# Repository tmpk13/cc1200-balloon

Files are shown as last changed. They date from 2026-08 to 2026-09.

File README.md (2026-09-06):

# cc1200-balloon

High altitude balloon payload: a CC1200 sub-GHz telemetry downlink and an air
quality sensor stack, hosted by a Seeed Wio-E5 module.

The CC1200 radio and its 434 MHz matching network are carried over from the
v1 design (an import of the Altus Metrum TeleMini netlist). Everything else -
the STM32F042 host, the flash, the barometer, the pyro channels, the LDO,
the comparator and the buzzer - has been removed and replaced by the Wio-E5,
a GNSS receiver and the sensor set from `Forest-Balloon.csv`.

Schematic only. There is no PCB layout yet.

## Architecture

```mermaid
classDiagram
    direction LR

    class WioE5["U201 Wio-E5"] {
        STM32WLE5JC + SX126x
        SPI1 PB3 PB4 PB5
        I2C1 PB6 PB7
        USART2 PA2 PA3
        LPUART1 PC1
        ADC_IN0 PB13
        RFIO to J201 coax pads
    }
    class Power["Power"] {
        J101 battery pads 3.6 V max
        Q101 reverse block
        Q102 P-FET load switch
        SW101 on/off on the gate
        +BATT unregulated
    }
    class Radio["U301 CC1200"] {
        40 MHz X301
        PA and LNA match
        J301 coax pads
        SPI + CS + RESET + GPIO2
    }
    class GNSS["U401 AT6558R-5N32"] {
        26 MHz TCXO X401
        32.768 kHz X402
        internal DCDC L403
        active antenna bias-T
        J401 coax pads
        UART0 + 1PPS + ON_OFF
        C414 optional supercap
    }
    class I2CBus["I2C1 at 100 kHz"] {
        U501 SCD40 CO2 0x62
        U502 AS3935 lightning 0x03
        U503 BME688 0x76
        U504 BME688 0x77
    }
    class SPIBus["SPI1"] {
        U301 CC1200
        J501 BMV080 particulate
    }
    class Antenna["L501 100 uH loop"] {
        C505 910p + C506 47p
        R501 10k damping
        500 kHz resonant
    }

    Power --> WioE5 : +BATT
    Power --> Radio : +BATT
    Power --> GNSS : +BATT
    Power --> I2CBus : +BATT
    Power --> SPIBus : +BATT
    Power --> WioE5 : VBAT_SENSE
    WioE5 --> SPIBus : SPI_SCK MISO MOSI
    WioE5 --> Radio : RADIO_CS RST IRQ
    WioE5 --> I2CBus : SCL SDA
    WioE5 --> GNSS : GNSS_TX RX PPS ONOFF
    I2CBus --> WioE5 : LIGHTNING_IRQ
    SPIBus --> WioE5 : PM_CS PM_IRQ
    Antenna --> I2CBus : INP/INN
```

The generator pipeline, which is what `build.sh` runs:

```mermaid
flowchart LR
    subgraph src[sources]
        sheets[sheets/*.json<br/>components, nets, groups]
        scad[models/*.scad]
        parts[tools/gen_bom.ts<br/>value to MPN map]
    end
    subgraph lib[libraries]
        sym[gen_symbols.ts<br/>Wio-E5, CC1200+pin16,<br/>AT6558R, BMV080]
        fp[gen_footprints.ts<br/>WIO-E5, FPC-13,<br/>QFN-40, axial coil]
        d3[gen_3d.ts<br/>OpenSCAD to STL to WRL]
    end
    subgraph gen[generation]
        kv[kicad-vis<br/>placement]
        asm[assemble.ts<br/>hierarchy + root sheet]
        loc[localize.ts<br/>demote sheet-local globals]
        flags[fixflags.ts]
        patch[patchnets.ts]
        flow[flowbridge.ts<br/>flow-wire routing]
        lbl[fixlabels.ts<br/>label justification]
    end
    subgraph check[gates]
        cg[checkglobals.ts]
        cs[checkshorts.ts]
        cf[checkframe.ts]
        vn[verify_nets.ts]
        erc[kicad-cli ERC]
    end
    subgraph out[outputs]
        sch[*.kicad_sch]
        bom[BOM.md<br/>digikey_bom.csv]
    end

    sheets --> kv
    sym --> kv
    fp --> kv
    scad --> d3
    d3 --> fp
    kv --> asm --> loc --> flags --> patch --> flow --> lbl --> sch
    sch --> cg & cs & cf & vn & erc
    parts --> bom
    sheets --> bom
```

## Sheets

| Sheet | Contents |
| --- | --- |
| `power.kicad_sch` | battery solder pads, P-FET reverse block, SPDT switch driving a second P-FET as a soft-start load switch, battery sense divider, 4 mounting holes |
| `mcu.kicad_sch` | Wio-E5 module, decoupling, reset, coax pads for the module's own LoRa radio, SWD + console pads, status LED, I2C pull-ups |
| `radio.kicad_sch` | CC1200, 40 MHz crystal, per-pin decoupling, loop filter, the v1 TX/RX matching network, coax pads |
| `gnss.kicad_sch` | AT6558R-5N32, 26 MHz TCXO, 32.768 kHz RTC crystal, internal DCDC/LDO passives, active-antenna bias-T, coax pads, optional RTC backup supercapacitor |
| `sensors.kicad_sch` | SCD40, AS3935 with its 500 kHz loop antenna, two BME688 at different addresses, BMV080 ZIF connector |

## Power

There is no regulator. The battery drives the whole board through two
P-channel FETs in series:

```
J101 -- VBAT_IN -- Q101 (reverse block) -- VBATT -- Q102 (load switch) -- +BATT
          |                                  |            |
        D101 TVS                           C101 22u    C104 10u + C106 22u
```

`Q101` blocks a reversed battery: its source is on the load side, so the
body diode conducts battery to load and the channel shorts it out. That is
also why `Q101` cannot double as the on/off switch - the body diode keeps
the load powered whatever the gate does.

`Q102` is the switch, oriented the other way round (source on the battery
side), so its body diode blocks in the forward direction and an open channel
really does disconnect the load. `SW101` drives its gate: pole to `SW_ON`,
one throw to GND (on), the other to `VBATT` (off), so the gate is defined in
both positions. `R101` 100k holds the gate at the source - off - while the
switch is between contacts.

`R102` 10k and `C102` 1u slow the turn-on to about 9 ms, which holds the
inrush to roughly 30 mA. Without them the switch would connect about 70 uF
of rail and IC decoupling straight across the cell; a bobbin lithium cell
with ohms of internal resistance would collapse and the board would sit in
a brownout loop. The regulator's own soft start used to do this job.

The 10k has to stay small against the 100k pull-up or the gate never gets
there: on, the two divide `VBATT` and leave the gate at 9 % of it, so
Vgs is -3.3 V at a full cell and still -2.3 V at 2.5 V.

The `+BATT` rail is the battery, minus two Rds(on) drops - about 100 mR
total, so a few tens of millivolts at the currents this board draws.
Everything runs from it directly, so the supply follows the cell all the way
from full charge to cutoff.

| | |
| --- | --- |
| Rail | `+BATT`, unregulated |
| Maximum | 3.6 V |
| Off-state drain | `Q102` and `Q101` leakage only; the sense divider is on the switched side |
| On-state overhead | 33 uA in the `R101`/`R102` gate divider, 18 uA in the `R103`/`R104` sense divider |

## Wio-E5 pin map

All 18 usable module GPIO are allocated. `PA13`/`PA14` are SWD, `RST` is on
the debug header.

| Pin | Net | Function |
| --- | --- | --- |
| 8 PB3 | `SPI_SCK` | SPI1 clock, CC1200 + BMV080 |
| 7 PB4 | `SPI_MISO` | SPI1 MISO |
| 11 PB5 | `SPI_MOSI` | SPI1 MOSI |
| 26 PB14 | `RADIO_CS` | CC1200 chip select |
| 5 PB15 | `RADIO_RST` | CC1200 reset |
| 20 PB10 | `RADIO_IRQ` | CC1200 GPIO2 |
| 6 PA15 | `PM_CS` | BMV080 chip select |
| 25 PB9 | `PM_IRQ` | BMV080 interrupt |
| 10 PB6 | `SCL` | I2C1 clock |
| 9 PB7 | `SDA` | I2C1 data |
| 23 PA0 | `LIGHTNING_IRQ` | AS3935 interrupt (wake-capable) |
| 19 PA2 | `GNSS_RX` | USART2 TX to the receiver |
| 18 PA3 | `GNSS_TX` | USART2 RX from the receiver |
| 27 PA10 | `GNSS_PPS` | 1PPS |
| 13 PC0 | `GNSS_ONOFF` | receiver shutdown control |
| 12 PC1 | `DBG_TX` | LPUART1 console out, on the debug header |
| 24 PB13 | `VBAT_SENSE` | ADC_IN0, 1:2 divider off the switched `+BATT` rail |
| 21 PA9 | `STATUS_LED` | green LED through 1 k |
| 15 RFIO | `LORA_RF` | u.FL, the module's own sub-GHz radio |

The CC1200's GPIO0 and GPIO3 go to test pads (`TP301`, `TP302`) rather than
to the MCU; one interrupt line is enough for normal operation and there were
no pins left.

## No connectors

The payload is mass-limited, so nothing on this board mates with anything.
Every interface is a solder pad:

| Pad | Was | Carries |
| --- | --- | --- |
| `J101` | JST-PH 2-pos | battery leads, 3.0 mm pitch, + marked in silkscreen |
| `J202` | 1x06 2.54 mm header | SWD and console, six 1.27 mm pads |
| `J301` | SMA edge launch | CC1200 coax pigtail |
| `J401` | SMA edge launch | GNSS coax pigtail |
| `J201` | u.FL receptacle | Wio-E5 LoRa coax pigtail |

That is roughly 5 g back, most of it the two SMA edge launches. The coax
pads are a centre-conductor land with coplanar grounds either side and a
braid pad behind, so a pigtail lies flat and strain-relieves on the braid
pad.

The one connector left is `J501`, the 0.30 mm ZIF that the BMV080's flex
plugs into. It weighs about 0.05 g and Bosch specifies no other way to
attach the sensor, so it stays.

## Antennas

Three RF ports, all separate, all soldered:

- `J301` - CC1200, matched for 434 MHz by the v1 network.
- `J401` - GNSS. Expects an **active** antenna: the AT6558R data sheet asks
  for 18-35 dB of external gain, and `L401`/`C401` form the bias-T that
  feeds it from `ANT_BIAS`, with `C402` blocking the feed DC out of `RF_IN`
  and `L402` the series match into it. The BOM names an Abracon AANI-AP-0158-1, a
  27 x 27 mm adhesive patch with a 28 dB LNA and a 100 mm pigtail; cut its
  u.FL plug off and solder the coax to the pads.
- `J201` - the Wio-E5's own LoRa radio, independent of the CC1200 link.

## Optional RTC backup

`C414` is an unpopulated supercapacitor on the AT6558R's `VDD_BK` pin, for
GNSS hot start after a power interruption. The chip trickle-charges it
through its own internal circuit, and blocks it from discharging back into
the rail - no diode or series resistor needed, so it wires straight to the
pin.

`VDD_BK` is left floating when `C414` is not fitted, which is what the data
sheet asks for. The backup domain is still powered whenever the board is:
the chip feeds it internally from `VDD_IO` through a diode. Only the
*unpowered* hold needs the supercapacitor.

The named part is a KEMET FCS0V104ZFTBR24, 100 mF at **3.5 V**, which is
below the 3.6 V the `+BATT` rail can reach. The data sheet wants a backup
cell rated above `VDD_IO` + 0.3 V, so above 3.9 V here; pick a
higher-voltage part before fitting it. 100 mF holds the RTC and backup RAM
for roughly three hours, and costs about 1 g and a 10.7 mm circle of board
- which is why it is optional on a mass-limited payload.

## Regenerating

```sh
./build.sh                 # libraries, sheets, routing, all gates, ERC, BOM
SKIP_SOURCING=1 ./build.sh # same, without the live DigiKey pass
bun run tools/gen_bom.ts   # bom.json from sheets/*.json
tools/source_bom.py --boards 1 --planned 8
```

`build.sh` is deterministic: same inputs, byte-identical schematics. Edit
`sheets/*.json`, never the generated `.kicad_sch`.

The BOM step is separate because it needs network access and spends DigiKey
API quota. It reads live stock and pricing, and will substitute an
equivalent in-stock part when the preferred one has run out - checking the
parametric value and package first, so a request for 1 uF cannot come back
as 0.1 uF.

`tools/source_bom.py` needs `digi-mouse-search` and its virtualenv, which is
not installed on this machine, so `build.sh` reports the missing interpreter
and stops short of the sourcing pass. `bom.json` is still regenerated; the
stock and price columns in `BOM.md` are whatever the last successful run
read. Re-run the sourcing pass before ordering.

## Verification

`build.sh` fails on any of these:

| Gate | Result |
| --- | --- |
| kicad-vis placement | 5/5 sheets placed |
| flow-wire routing | 5/5 sheets, DRC 0 violations |
| cross-sheet global labels | no undeclared names shared between sheets |
| shorted rails | no electrical group carries two power symbols |
| footprint resolution | 27 distinct footprints, all present |
| frame fit | no sheet's content runs off its page |
| netlist vs `sheets/*.json` | 352 endpoints, 74 nets, exact match |
| full-hierarchy ERC | 0 errors, 2 warnings |

The two ERC warnings are the BME688 address straps: `U503.SDO` to GND and
`U504.SDO` to +BATT put a bidirectional pin on a power net, which is what
setting an I2C address on that part looks like.

The netlist comparison is the gate that matters. Placement and routing are
geometry, and geometry can join two rails without ERC calling it an error -
which is exactly what happened once during this design (see `NOTES.md`).

## Ordering

`digikey_bom.csv` holds **one board's worth**: 49 lines, three columns,
every line cut tape or bulk. Upload it to DigiKey's BOM Manager and set the
multiplier there rather than scaling the file - that way the pack and reel
rounding happens once, in DigiKey's hands, instead of being baked in here.

Two lines are deliberately absent from the CSV, because DigiKey cannot
fulfil them as uploaded:

- **C414** (supercapacitor) - do not populate; `399-13093-1-ND` if you want it.
- **U401 AT6558R-5N32** - not stocked at DigiKey at all. LCSC C500608.

Cost is $118.98 per board, of which $45 is off-board (the BMV080 module and
the GNSS antenna). Checked against an 8-board run, two lines are tight:
the BMV080 comes in packs of 10 and is discontinued at DigiKey, and the
56 nH match inductor has 59 in stock against the 16 the run needs.

## Known limitations

- **The rail is unregulated and can touch 3.6 V.** That is the absolute
  maximum operating supply for both the Wio-E5's STM32WLE5 and the CC1200,
  so there is no headroom left: a cell that rests above 3.6 V, or a charger
  left connected, is over the limit. Confirm the cell's open-circuit voltage
  before connecting it.
- **No brownout floor either.** With the regulator gone the rail falls with
  the cell instead of holding 3.3 V to cutoff, so the RF output power, the
  ADC reference and the sensor readings all drift over a flight. `VBAT_SENSE`
  measures the rail itself, which at least makes the drift observable.
- **The GNSS goes out of spec before the rest of the board.** `VDD_IO` and
  `DX_IN` on the AT6558R are specified 2.7-3.6 V, and its power-on reset
  releases at about 2.45 V. The receiver is therefore the first thing to
  stop as the cell sags, and it stops without warning the MCU - budget the
  flight on the 2.7 V point, not on the cell's cutoff.
- **`D101` no longer protects the ICs.** The SMF6.5A was sized for the old
  1.8-5.5 V regulator input; it does not start conducting until about 7 V,
  well past the 3.9 V absolute maximum of the parts now sitting directly on
  the rail. It is a gross-overvoltage guard, not IC protection, and no
  standoff low enough to help would sit safely above a fresh cell.
- **GNSS altitude limit.** The AT6558R data sheet says nothing about COCOM
  limits. Most consumer receivers stop reporting above 18 km or 515 m/s,
  which is below balloon float altitude. Confirm the firmware's behaviour
  before flying, or plan on a receiver with an explicit airborne mode.
- **BMV080 mating connector.** The land pattern for the 0.30 mm pitch
  KYOCERA 6844 connector was derived from the series drawing, not from a
  vendor-supplied library. Check it against Kyocera's own recommendation
  before fabrication.
- **SCD40 in a balloon.** The sensor is specified from -10 C and its NDIR
  reading is pressure-dependent; at float altitude both are out of range
  without compensation from the BME688 pressure channel.
- No PCB layout, no thermal design, no antenna measurements.

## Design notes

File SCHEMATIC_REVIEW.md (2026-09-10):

# Schematic review: cc1200-balloon

Reviewed at commit `0d6f3e7` ("Clean up schematic. Add component groups to PCB.").
Reference design for the CC1200 supply work: `~/telemini/` (Altus Metrum TeleMini 3.0a).

## Verdict

Two blocking defects, both introduced by the hand-edit in `0d6f3e7`:

1. **The Power sheet has been emptied.** Ten parts were deleted, including the
   on/off switch and the entire load-switch path. The board has no way to be
   turned off and no bulk capacitance at the load.
2. **`SCL` and `SDA` are swapped at all four I2C devices.** The bus cannot work
   as drawn.

Everything else checks out. Outside those two faults the schematic is an exact
electrical match to `sheets/*.json`, the CC1200 support circuitry and the
434 MHz match reproduce TeleMini component-for-component, and the AT6558R
wiring matches the data sheet in `ref/`.

The PCB has **zero routed traces**, so fixing both costs no layout rework.

## Method

- Exported the flat netlist from the current `.kicad_sch` set with
  `kicad-cli sch export netlist` (107 components, 92 nets).
- Compared the resulting pin-to-net partition against `sheets/*.json`, the
  generator's source of truth, normalising the pin numbering of two-pin
  passives so that a flipped capacitor does not read as a difference.
- Cross-checked the CC1200 support parts and the RF match against the TeleMini
  netlist, and its capacitor placement against `telemini.pcb` element geometry.
- Checked the AT6558R against `ref/AT6558R-5N32.pdf` (pin table section 2.2,
  power scheme 3.2, reference design 7.1, BOM 7.2).
- Parsed `cc1200_balloon.kicad_pcb` and confirmed its net assignments match the
  schematic exactly, then measured every CC1200 support part's pad-to-pin
  distance.

Full-hierarchy ERC reports **0 violations**. Neither defect below is the kind
ERC can see: a swapped pair of same-type pins and a deleted subcircuit both
leave a perfectly legal schematic.

---

## 1. The Power sheet is empty (blocking)

`power.kicad_sch` is a 301-byte stub with no components. Some of its parts
migrated into `mcu.kicad_sch`; the rest were deleted outright.

| Ref | Value | Function | Status |
| --- | --- | --- | --- |
| `J101` | BATT pads | battery input | moved to MCU sheet |
| `Q101` | DMG3401LSN-7 | reverse-block P-FET | moved to MCU sheet |
| `R103` `R104` `C107` | 100k 100k 100n | battery sense divider | moved to MCU sheet |
| `H101`-`H104` | M2.5 | mounting holes | moved to MCU sheet |
| `D101` | SMF6.5A | input TVS | **deleted** |
| `C101` | 22u | `VBATT` bulk | **deleted** |
| `SW101` | JS102011SAQN | on/off switch | **deleted** |
| `Q102` | DMG3401LSN-7 | load switch P-FET | **deleted** |
| `R101` `R102` `C102` | 100k 10k 1u | gate bias and soft start | **deleted** |
| `C104` `C106` | 10u 22u | `+BATT` bulk | **deleted** |
| `C203` | 10u | Wio-E5 bulk (MCU sheet) | **deleted** |

Consequences:

- **No power switch.** The board is live whenever the cell is connected.
- **No soft start.** The `R102`/`C102` ramp that held inrush to ~30 mA is gone.
- **No input TVS.**
- **`VBATT` and `+BATT` have merged.** `Q101` source now feeds `+BATT`
  directly. Reverse-battery protection survives — that was `Q101`'s job — but
  it is now the only thing between the cell and the whole board.
- **The rail lost 42 uF of its 76 uF.** `+BATT` is down to 34 uF, and 22 uF of
  that is `C502` at the SCD40, 13.6 mm away from the CC1200. The radio's own
  local bulk is `C312`, a single 1 uF at 5.2 mm. That is thin for a part that
  pulls ~120 mA in TX bursts from a bobbin cell with ohms of internal
  resistance — the exact brownout loop `README.md` describes.

```mermaid
flowchart LR
    subgraph des["as designed in sheets/*.json"]
        J1[J101] --> D1[D101 TVS] --> Q1[Q101<br/>reverse block]
        Q1 --> VB[VBATT<br/>C101 22u]
        VB --> Q2[Q102<br/>load switch]
        SW[SW101 + R101<br/>R102 + C102] --> Q2
        Q2 --> BT[+BATT<br/>C104 10u + C106 22u]
    end
    subgraph drw["as drawn in the schematic today"]
        J1b[J101] --> Q1b[Q101<br/>reverse block] --> BTb[+BATT<br/>no local bulk]
    end
```

**Fix.** Restore the deleted parts. `sheets/power.json` still holds the correct
netlist for all of them, so the content is not lost — see section 5 for how to
get it back without losing the PCB work.

---

## 2. SCL and SDA are swapped at every I2C device (blocking)

The MCU end is right and all four device ends are wrong, so the clock line
lands on the sensors' data pins and vice versa.

| Net as drawn | MCU | SCD40 `U501` | AS3935 `U502` | BME688 `U503`/`U504` |
| --- | --- | --- | --- | --- |
| `SCL` | pin 10 `PB6` — clock, correct | pin 10 **SDA** | pin 13 **MOSI/SDA** | pin 3 **SDI** |
| `SDA` | pin 9 `PB7` — data, correct | pin 9 **SCL** | pin 11 **SCL** | pin 4 **SCK** |

`sheets/sensors.json` has it right (`SCL` to `U501.9 U502.11 U503.4 U504.4`),
so this is a regression introduced when the sheet was edited by hand, not a
source error. The pull-ups `R203`/`R204` follow the swapped nets, so both lines
are still pulled up — nothing else masks it.

**Fix.** The whole error is two global labels in `sensors.kicad_sch`:

- `SDA` at `328.93, 269.24`
- `SCL` at `328.93, 274.32`

Swapping those two label texts corrects all four devices at once. The board
carries the same swap (PCB nets match the schematic exactly), so re-import the
netlist afterwards — with no traces routed, nothing else has to move.

---

## 3. Everything else verified correct

These were checked against a reference and found sound; no action needed.

**CC1200 `U301`** — all 33 pins match the data sheet function assignment and
the TeleMini wiring: supplies on pins 1/5/12/13/15/22/25/27/28, the four
internal-regulator decoupling pins 6/21/26/29, `RBIAS` 56k on pin 14, the
1.8 nF loop filter across LPF0/LPF1 (23/24), `EXT_XOSC` (32) grounded for
crystal operation, and the exposed pad on GND.

**434 MHz match** — reproduces TeleMini node for node, including the two easy
things to get wrong: `C322` 2p2 sits in *parallel* with `L302` 15n (TeleMini
`C176` across `L172`), and `L307` 27n shunts LNA_P to ground while `L308` 27n
returns LNA_N to the RX node. All sixteen values carry over unchanged.

**AT6558R `U401`** — matches `ref/AT6558R-5N32.pdf` throughout. `VDD_IO` (7)
and `DX_IN` (21) on the rail; `VCORE` (23) fed from `DX_OUT` (22) through
`L403`; the LDO output pins each decoupled to the value the pin table names
(`VDD_ANA` 1 uF, `VX_OUT` 0.1 uF); `TEST` (29) pulled low and `ON_OFF` (30)
driven, both as specified; `nRST` (17), `GPIO8` (8) and `GPIO16` (33) left
floating, which is what the data sheet requires. The 32.768 kHz crystal
correctly has no load caps. `ANT_BIAS` uses the 33 nH + 0.1 uF feed the data
sheet names.

**UART crossing** — `PA2` (USART2 TX) reaches `GPIO1/RXD0`, `PA3` (USART2 RX)
reaches `GPIO0/TXD0`, each through the 22R the reference design shows. Correct
in the direction that is usually wrong.

**I2C addressing** — AS3935 `AD0`/`AD1` both high gives 0x03; BME688 `SDO` low
gives 0x76 and high gives 0x77; both BME688 `CSB` pins high select I2C. All
match `README.md`.

**Interrupts** — `PA0`, `PB9`, `PB10` use EXTI lines 0, 9 and 10. No two
interrupt sources share a line.

**Status LED** — `D201` cathode to GND, anode through `R202` 1k to `PA9`.
Correct polarity for a high-side drive.

---

## 4. Worth confirming before fabrication

Three items I could not settle from material on this machine.

**AS3935 regulator configuration.** `Vdd` (5) and `VReg` (6) are both tied to
`+BATT` with `EN` (7) grounded — the "internal regulator bypassed" arrangement,
which the ams application circuits specify for a *regulated 2.5 V* supply, not
for a rail that reaches 3.6 V. There is no AS3935 data sheet in `ref/` and
`NOTES.md` does not record the reasoning. Check whether this part wants
`EN_VREG` tied high on an unregulated rail. Separately, `C503` (10u) sits on
`ACG` (1) rather than on `VReg`; confirm that is where the data sheet wants it.

**CC1200 crystal load caps.** `C318`/`C319` are 12p against TeleMini's 10p, and
the crystal changed with them (`CX3225SB40000D0FPLCC` here, an ABM12 in
TeleMini). `NOTES.md` says the load caps were "kept from v1", which is not
quite what happened. Size them from the chosen crystal's CL: with ~3 pF of
stray, 12 pF caps present about 9 pF, so they suit a CL=9 pF part and pull a
CL=8 pF part low.

**`BOM.md` is stale.** It lists `C402` as 1u and `C411` as 10u, and references
`C417`-`C419`, none of which match `sheets/gnss.json` today. Regenerate before
ordering.

---

## 5. CC1200 supply decoupling: which capacitor goes at which pin

This is the layout list. The schematic puts all nine 47 nF caps on one `+BATT`
net with no pin association, so the assignment has to be made here and carried
into placement by hand.

`U301` is a QFN-32, 5x5 mm, 0.5 mm pitch, at `90.0, 108.65` rotated -90 deg on
`F.Cu`. Pin coordinates below are the board coordinates as placed today.

### The nine rail capacitors — one per supply pin

Assignment follows refdes order against pin order, which is how `NOTES.md`
describes the intent ("the nine supply decoupling caps"):

| Cap | Value | Pin | Function | Pad at | Package edge |
| --- | --- | --- | --- | --- | --- |
| `C301` | 47n | 1 | `VDD_GUARD` | `91.75, 106.21` | top |
| `C302` | 47n | 5 | `DVDD` | `89.75, 106.21` | top |
| `C303` | 47n | 12 | `DVDD` | `87.56, 108.40` | left |
| `C304` | 47n | 13 | `AVDD_IF` | `87.56, 108.90` | left |
| `C305` | 47n | 15 | `AVDD_RF` | `87.56, 109.90` | left |
| `C306` | 47n | 22 | `AVDD_SYNTH1` | `90.75, 111.09` | bottom |
| `C307` | 47n | 25 | `AVDD_PFD_CHP` | `92.44, 110.40` | right |
| `C308` | 47n | 27 | `AVDD_SYNTH2` | `92.44, 109.40` | right |
| `C309` | 47n | 28 | `AVDD_XOSC` | `92.44, 108.90` | right |

Each one goes on the same layer as the part, hot pad facing its supply pin,
ground pad onto the ground pour with its own via — never daisy-chained through
a neighbour's via. The nine pins sit on all four edges of the package, so the
caps must ring it. TeleMini achieved 0.8-2.2 mm pad-to-pin; treat 2 mm as the
ceiling.

TeleMini used seven 47 nF for these nine pins, letting one cap serve pins 27
and 28 and another serve 12 and 13. This design has nine, one each, which is
the better arrangement — keep it.

### The four internal-regulator capacitors — closest of all

These decouple regulators *inside* the chip. They are not on the rail, and they
matter more than the nine above.

| Cap | Value | Pin | Function | Pad at | TeleMini equivalent |
| --- | --- | --- | --- | --- | --- |
| `C313` | 220n | 6 | `DCPL` | `89.25, 106.21` | `C42` 0.22uF |
| `C314` | 10n | 21 | `DCPL_VCO` | `90.25, 111.09` | `C211` 0.01uF |
| `C315` | 47n | 26 | `DCPL_PFD_CHP` | `92.44, 109.90` | `C261` 47nF |
| `C316` | 47n | 29 | `DCPL_XOSC` | `92.44, 108.40` | `C291` 47nF |

`C314` on `DCPL_VCO` is the one to place first — it is the VCO's supply and it
sits on the bottom edge between the LNA pins and `AVDD_SYNTH1`, which is
crowded. TeleMini got all four to 2.0-3.4 mm.

### Rail-level capacitors — not per-pin

| Cap | Value | Where it goes |
| --- | --- | --- |
| `C312` | 1u | bulk, where `+BATT` enters the radio block, ahead of the ring of 47n |
| `C311` | 10n | with `C312`, or near `AVDD_RF` (pin 15) — TeleMini's `C171` was closest to that pin |
| `C310` | 100p | near `AVDD_RF` (pin 15) — TeleMini's `C172`, the fastest cap in the set |

**`C320` (56p) is not a decoupling capacitor.** It sits in parallel with `R302`
18R across the PA bias feed, exactly as TeleMini's `C173` parallels `R171`.
Place it beside `R302`, not at a chip pin.

### Also close to their pins

`C317` 1n8 straddles pins 23/24 with the shortest possible loop; `C318`/`C319`
and `X301` form the 40 MHz oscillator at pins 30/31; `R301` 56k sits at pin 14.

### What the current PCB does

All twelve rail capacitors are bunched off the top edge of the package, and the
four regulator capacitors are 6-11 mm away:

| Part | Should be at | Nearest supply pin today | Distance |
| --- | --- | --- | --- |
| `C301`-`C309` | ringing the package | pins 1 and 5 only, all nine | 2.1-4.8 mm |
| `C310` `C311` `C312` | rail entry / pin 15 | pins 1 and 5 | 4.6-5.3 mm |
| `C313` | pin 6 | — | 6.2 mm |
| `C314` | pin 21 | — | 11.1 mm |
| `C315` | pin 26 | — | 9.7 mm |
| `C316` | pin 29 | — | 10.0 mm |

Nothing is placed on the left, bottom or right edges. Pins 12, 13, 15, 22, 25,
27 and 28 have no capacitor near them at all. This needs redoing before the
board is routed.

Better already: `R301` at 1.4 mm, `C319` at 1.4 mm, `C318` at 1.9 mm, `C317` at
1.7-2.0 mm, `C325` at 1.9 mm. The TX chain is loose — `L301` 5.4 mm and `C321`
6.2 mm from pin 17 — and should be tightened while the decoupling is moved.

---

## 6. Suggested order of work

1. Swap the two global labels in `sensors.kicad_sch` — smallest fix, largest
   consequence.
2. Restore the power section. `sheets/power.json` is intact, so the cleanest
   route is to regenerate `power.kicad_sch` alone rather than running
   `build.sh`, which rewrites all five sheets and would discard the rest of the
   hand-editing in `0d6f3e7`. Restore `C203` on the MCU sheet at the same time.
3. Re-import the netlist into the PCB and place the restored parts.
4. Redo the CC1200 decoupling placement per section 5 before routing.
5. Resolve the three items in section 4.
6. Regenerate `BOM.md`.

### A note on the generator

`sheets/*.json` and the `.kicad_sch` files have diverged: the schematics are
now hand-edited and the JSON is not. `build.sh` regenerates all five sheets
from the JSON unconditionally, so running it restores the power section and the
correct I2C wiring but discards every other change made in `0d6f3e7`. Decide
which direction is authoritative before running it. (`assemble.ts` merges into
`.kicad_pro` rather than overwriting it, so the ERC pin map and severities
configured in the GUI are safe either way.)

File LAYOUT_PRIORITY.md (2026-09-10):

# CC1200 layout: what to keep short, in priority order

Companion to `SCHEMATIC_REVIEW.md`. Measured against the working tree on top of
`d4266bb`, with `U301` at `66.15, 138.95` rotated -90 deg.

**Context.** All 41 radio-block parts are currently staged outside the board
outline (the outline is 50 x 30 mm at x 75..125, y 85..115). The relative
placement inside the block is already largely right — the nine supply caps ring
the package at 1.2-2.0 mm and the match chain's internal hops are 1.0-1.6 mm.
What follows is the order to preserve when the block is brought onto the board.

## The number that sets the ranking

A narrow trace over a plane runs about **0.8 nH/mm**, and a via adds about
0.4 nH. At 434 MHz that is **~2.2 ohm of series reactance per millimetre**.

The same millimetre costs different amounts depending on what it is in series
with, which is the whole basis of the ranking below:

- **In a decoupling path** it lowers the capacitor's self-resonant frequency.
  A 47n 0402 has ~0.7 nH of its own ESL and resonates near 28 MHz. Add 2 mm of
  trace and a via — 2.0 nH — and it resonates near 14 MHz instead. The cap is
  half as effective at exactly the frequencies the chip's internal regulators
  care about, and the schematic looks identical.
- **In the match network** it is an unplanned series element. `C322` is 2.2 pF
  and `L302` is 15 nH; a stray 4 nH between them is a 27 % error in the
  inductor.
- **On the 40 MHz reference** it is mostly stray capacitance pulling frequency,
  and a crosstalk aperture. Reference phase noise multiplies to the carrier by
  20*log10(434/40) = **+20.7 dB**.
- **On SPI at 10 MHz** it costs nothing measurable.

---

## The ranking

| # | Keep short | Target | Now | Status |
| --- | --- | --- | --- | --- |
| 1 | `GND_EP` (33) down to the ground planes | via array in the pad | **0 vias** | **do first** |
| 2 | `C314` 10n to pin 21 `DCPL_VCO` | <=1.0 mm | 1.23 mm | close |
| 3 | `C316` 47n to pin 29 `DCPL_XOSC` | <=1.0 mm | 2.10 mm | tighten |
| 4 | `C315` 47n to pin 26 `DCPL_PFD_CHP` | <=1.0 mm | 3.09 mm | tighten |
| 5 | `C313` 220n to pin 6 `DCPL` | <=1.5 mm | 2.63 mm | tighten |
| 6 | `L301` 56n to pin 17 `PA` | <=1.5 mm | 6.22 mm | **worst in TX** |
| 7 | `C325`/`L306`/`L307`/`C326`/`L308` to pins 19/20, **P and N matched** | <=2.0 mm, legs within 0.3 mm | 1.8-6.0 mm, unbalanced | **worst in RX** |
| 8 | `C323` 5p1 to pin 18 `TRX_SW` | <=1.5 mm | 6.62 mm | tighten |
| 9 | `X301` + `C318`/`C319` to pins 30/31 | xtal <=2.5 mm, caps between | 4.0-5.5 mm | tighten |
| 10 | `R301` 56k to pin 14 `RBIAS` | <=2.0 mm | 3.31 mm | tighten |
| 11 | `C317` 1n8 across pins 23/24 `LPF0`/`LPF1` | <=1.5 mm | 1.4-1.6 mm | ok |
| 12 | Analog rail caps: pins 15, 28, 22, 27, 25, 13 | <=1.5 mm | 1.33-1.81 mm | ok, see note |
| 13 | Digital rail caps: pins 5, 12, 1 | <=2.0 mm | 1.21-1.79 mm | ok |
| 14 | Match chain internal hops, in schematic order | <=2.0 mm each | 1.0-1.6 mm | ok |
| 15 | `C310` 100p, rail | <=3 mm, near pin 15 | 7.64 mm | bring in |
| 16 | `C311` 10n / `C312` 1u, rail bulk | <=8 mm | 6.6 / 5.5 mm | ok |
| 17 | `L304` to `J301`, the only 50-ohm section | impedance, not length | 3.22 mm | see note |
| 18 | SPI (7,8,9,11), `RESET_N` (2), GPIO (3,4,10), test points | no constraint | — | route last |

---

## Why each tier sits where it does

### 1. The exposed pad, before anything else

`GND_EP` is the return path for every current in the chip, so it defines what
"short" even means for the seventeen items below it. Until it is solid,
tightening a decoupling cap buys less than the measurement suggests: the cap's
ground has to travel laterally around the package to find a via, and that path
is in series with the cap.

The pad is set up correctly in the footprint — 3.45 mm, `pad_prop_heatsink`,
`zone_connect 2`, on the `GND` net — and the `GND` zone is poured on all four
layers. But there are **4 vias on the entire board** and none of them are in
the pad, so the pad currently only reaches the `F.Cu` pour. Put a via array in
it (a 3x3 of 0.3 mm drill on ~1.2 mm pitch fits the 3.45 mm pad) and add a ring
of ground vias just outside the pin ring, tightest along the RF edge.

This is also the item with the shortest length that matters: the ~1.5 mm of
via barrel from the pad to `In1.Cu`.

### 2-5. The four `DCPL` pins

These are **not** rail decoupling. They are the outputs of regulators inside
the chip, and their capacitors are those regulators' compensation. Series
inductance here does not just filter worse, it moves a pole in a control loop
that was compensated assuming a low-impedance capacitor.

They rank above the RF path because they sit upstream of it — the VCO
regulator's noise is on the carrier before the carrier ever reaches pin 17.
Within the four:

- **`DCPL_VCO` (21)** — the VCO supply. Straight to phase noise and spurs.
- **`DCPL_XOSC` (29)** — the reference oscillator's supply, and whatever lands
  here gets the +20.7 dB multiplication to 434 MHz.
- **`DCPL_PFD_CHP` (26)** — inside the PLL loop, so in-band.
- **`DCPL` (6)** — digital core. Least sensitive of the four, but still a
  regulator output.

`C314` is already at 1.23 mm; the other three drifted when the block was
rearranged. Note `DCPL_VCO` (21) sits on the bottom edge wedged between the LNA
pins and `AVDD_SYNTH1` — it is the crowded one, so place it before its
neighbours rather than after.

### 6-8. The RF pins

`L301` at pin 17 is the first element of the TX match and carries both the DC
supply and the full RF output. 6.22 mm of trace is ~5 nH against a 56 nH
element — a 9 % error in the value that sets the PA's load impedance, which
comes straight off output power and efficiency. Since the stated job of this
board is a telemetry **downlink**, that is the millimetre that costs the most
link budget, which is why it ranks above the LNA.

The LNA pair at 7 has two separate requirements and the second is easy to miss:

- **Short**, because loss ahead of the LNA adds to noise figure dB for dB.
- **Balanced**, because the LNA is differential. `L306` 56n bridges pins 19 and
  20 and should straddle them symmetrically; `L307`/`C325` on the P leg and
  `L308`/`C326` on the N leg should mirror each other. Right now the P leg
  averages 4.22 mm and the N leg 4.66 mm with individual parts from 1.8 to
  6.0 mm, so the two legs are visibly unequal. Imbalance converts common-mode
  noise into differential signal and degrades image rejection, and no amount of
  tuning the values fixes it.

If uplink or commanding matters as much as the downlink, swap 6 and 7.

`C323` at pin 18 carries full TX power through the switch node in transmit.
`L305` is already fine at 2.05 mm; `C323` is the one at 6.62 mm.

### 9-10. The high-impedance nodes

The 40 MHz crystal group is now the worst-placed sensitive cluster —
`X301` 5.46 mm, `C318` 4.13 mm, `C319` 3.96 mm. Two things go wrong at that
distance: stray capacitance adds to a 12 pF load and pulls the frequency, and
a long high-Q node is both a crosstalk victim and an aggressor. Put the load
caps *between* the crystal and the pins, not beyond the crystal, and return
their grounds into the same via region as the exposed pad. The load caps are
also worth re-checking against the crystal's CL — see section 4 of the review.

`R301` is 56k, which makes `RBIAS` the highest-impedance node on the part and
the best antenna on the board. It sets every internal bias current. Keep it
under 2 mm, and keep it away from the crystal and the match chain rather than
merely short.

### 11-13. Decoupling and the loop filter

`C317` across the loop filter pins is already good. The nine rail caps are the
part of the current placement that is already right: every supply pin has a
47n within 1.21-1.97 mm and they ring all four edges.

One reassignment worth making: **`C308` is currently serving both pin 12
(1.79 mm) and pin 13 (1.81 mm) while `C309` sits redundantly near pin 12
(1.97 mm, and 2.24 mm from pin 13).** Move `C309` onto pin 13 `AVDD_IF` so each
of the nine pins has its own cap, which is what the nine were bought for.
Ground each cap with its own via — never daisy-chain two caps through one.

Analog pins rank above digital ones because `AVDD_RF`, `AVDD_XOSC`,
`AVDD_SYNTH1/2` and `AVDD_PFD_CHP` feed the blocks whose noise ends up on the
carrier, while `DVDD` and `VDD_GUARD` feed logic.

### 14. The chain, not the parts

The match network's internal hops are already 1.0-1.6 mm and in schematic
order. Preserve that as a block when it moves. The failure mode is spreading
the chain out or reordering it — the lumped values assume the elements are
adjacent.

### 17. The one place length is the wrong question

Everything from pin 17 through `L304` runs at match-network impedances that are
not 50 ohm, so "controlled impedance" is meaningless there and short is the
only rule. **`L304` to `J301` is the exception** — that section is at 50 ohm and
should be a proper coplanar microstrip with ground either side and stitching
vias along it. Getting its impedance right matters more than shaving a
millimetre off it.

### 18. Everything else

SPI, reset, the GPIO test points and `EXT_XOSC` have no length constraint worth
naming at these speeds. Route them last and use them as the escape path. The
only rule is negative: keep them out of the crystal area and do not let them
cross the LNA or PA traces.

---

## Suggested order of work

1. Via array in `GND_EP`, plus a ground via ring outside the pin ring.
2. Bring the radio block onto the board as a unit, keeping its internal
   arrangement.
3. Tighten `C315`, `C316`, `C313` onto their pins.
4. Pull `L301`/`C321` and `C323` up to pins 17 and 18.
5. Rebuild the LNA cluster symmetrically about pins 19/20.
6. Bring the crystal group in to <=2.5 mm.
7. `R301` to <2 mm, `C310` to <3 mm.
8. Move `C309` onto pin 13.
9. Route the 50-ohm run to `J301` last, with stitching.

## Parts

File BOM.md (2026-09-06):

# cc1200-balloon bill of materials

52 lines, 117 placements.

**Quantities are for 1 board. Set the multiplier in DigiKey's BOM Manager rather than scaling this file** - per-line quantities here are one board's worth, and nothing is rounded up to a pack or a reel.

DigiKey stock and pricing read live; totals are indicative, not a quote.

**STALE - do not order from this file.** It still describes the GNSS sheet as it was before the 2026-09-06 AT6558R rewiring, so its designators, quantities and line count are all wrong (`C415`-`C422`, `R404`, `R405` no longer exist; `C414`, `R402`, `R403` and the new inductor and oscillator part numbers are missing). Offers were read on 2026-08-25 and the sourcing pass cannot run on this machine (`/home/tmpk/digi-mouse-search` is gone), so nothing here can be refreshed until it is reinstalled. `bom.json` is current and correct. Re-run `tools/source_bom.py` before ordering.

**Board total (excluding DNP): $118.98**

| Refs | Value | MPN | Manufacturer | Package | Qty | DigiKey | Packaging | Stock | Unit | Source |
| --- | --- | --- | --- | --- | --- | --- | --- | --- | --- | --- |
| C101 C106 C502 | 22u | LMK212BBJ226MD-T | Taiyo Yuden | C_0805_2012Metric | 3 | 587-5917-1-ND | Cut Tape (CT) | 7124 | $0.3000 | substituted |
| C102 C202 C312 C402 C405 C409 C412 C417 C418 C419 C504 C511 C512 C513 | 1u | LMK105BJ105KVHF | Taiyo Yuden | C_0402_1005Metric | 14 | 587-3712-1-ND | Cut Tape (CT) | 754503 | $0.0560 | substituted |
| C104 C203 C411 C503 | 10u | GRM188R60J106KE47D | Murata Electronics | C_0603_1608Metric | 4 | 490-12538-1-ND | Cut Tape (CT) | 49549 | $0.1200 | substituted |
| C107 C201 C204 C403 C404 C406 C407 C408 C410 C413 C420 C421 C501 C507 C508 C509 C510 C514 | 100n | CL05B104KO5NNNC | Samsung Electro-Mechanics | C_0402_1005Metric | 18 | 1276-1001-1-ND | Cut Tape (CT) | 3698775 | $0.0170 | substituted |
| C301 C302 C303 C304 C305 C306 C307 C308 C309 C315 C316 | 47n | GRM155R71H473KE14D | Murata Electronics | C_0402_1005Metric | 11 | 490-10702-1-ND | Cut Tape (CT) | 990298 | $0.0230 | preferred |
| C310 C414 | 100p | GRM1555C1H101JA01D | Murata Electronics | C_0402_1005Metric | 2 | 490-5922-1-ND | Cut Tape (CT) | 504137 | $0.1100 | preferred |
| C311 C314 | 10n | GRM155R71H103KA88D | Murata Electronics | C_0402_1005Metric | 2 | 490-4516-1-ND | Cut Tape (CT) | 3203045 | $0.1000 | preferred |
| C313 | 220n | CL05A224KA5NNNC | Samsung Electro-Mechanics | C_0402_1005Metric | 1 | 1276-1455-1-ND | Cut Tape (CT) | 1670 | $0.1300 | preferred |
| C317 | 1n8 | GRM1555C1H182JA01D | Murata Electronics | C_0402_1005Metric | 1 | 490-GRM1555C1H182JA01DCT-ND | Cut Tape (CT) | 155404 | $0.1000 | preferred |
| C318 C319 | 12p | CL05C120JB5NNNC | Samsung Electro-Mechanics | C_0402_1005Metric | 2 | 1276-1178-1-ND | Cut Tape (CT) | 135682 | $0.1000 | preferred |
| C320 | 56p | GRM1555C1H560JA01D | Murata Electronics | C_0402_1005Metric | 1 | 490-1288-1-ND | Cut Tape (CT) | 907472 | $0.1000 | preferred |
| C321 | 39p | CC0402JRNPO9BN390 | YAGEO | C_0402_1005Metric | 1 | 311-1009-1-ND | Cut Tape (CT) | 239185 | $0.1000 | substituted |
| C322 | 2p2 | GRM1555C1H2R2CA01D | Murata Electronics | C_0402_1005Metric | 1 | 490-5932-1-ND | Cut Tape (CT) | 1537 | $0.1000 | preferred |
| C323 C325 C326 | 5p1 | GJM1555C1H5R1CB01D | Murata Electronics | C_0402_1005Metric | 3 | 490-3102-1-ND | Cut Tape (CT) | 167984 | $0.1000 | substituted |
| C324 | 6p2 | GJM1555C1H6R2BB01D | Murata Electronics | C_0402_1005Metric | 1 | 490-11231-1-ND | Cut Tape (CT) | 446597 | $0.1000 | substituted |
| C401 | 470p | GRM1555C1H471JA01D | Murata Electronics | C_0402_1005Metric | 1 | 490-1297-1-ND | Cut Tape (CT) | 654811 | $0.1000 | preferred |
| C415 C416 | 10p | GRM1555C1H100JA01D | Murata Electronics | C_0402_1005Metric | 2 | 490-5921-1-ND | Cut Tape (CT) | 435236 | $0.1000 | DNP preferred |
| C422 | 100m | FCS0V104ZFTBR24 | KEMET | SuperCap_KEMET_FCS_D10.7mm | 1 | 399-13093-1-ND | Cut Tape (CT) | 516 | $4.1300 | DNP preferred |
| C505 | 910p | GCM1555C1H911FA16J | Murata Electronics | C_0402_1005Metric | 1 | 490-GCM1555C1H911FA16JCT-ND | Cut Tape (CT) | 62670 | $0.1000 | substituted |
| C506 | 47p | CC0402JRNPO9BN470 | YAGEO | C_0402_1005Metric | 1 | 311-1021-1-ND | Cut Tape (CT) | 459310 | $0.1000 | substituted |
| D101 | SMF6.5A | SMF6.5A-TP | MCC (Micro Commercial Components) | D_SOD-123F | 1 | SMF6.5A-TPMSCT-ND | Cut Tape (CT) | 67741 | $0.4100 | preferred |
| D201 | STATUS | LTST-C191KGKT | Lite-On Inc. | LED_0603_1608Metric | 1 | 160-1446-1-ND | Cut Tape (CT) | 2695092 | $0.1500 | preferred |
| J401 | GNSS antenna | AANI-AP-0158-1 | Abracon LLC | mates J401 | 1 | 535-AANI-AP-0158-1-ND | Bulk | 465 | $7.2600 | off-board |
| J501 | BMV080 | 046844713002846+ | KYOCERA AVX | Kyocera_046844713002846_FPC-13_P0.30mm | 1 | 478-046844713002846+CT-ND | Cut Tape (CT) | 27269 | $0.8000 | preferred |
| J501 | BMV080 | BMV080 | Bosch Sensortec | mates J501 | 1 | 828-BMV080-10PC-ND | Box | 610 | $37.8680 | off-board |
| L301 L306 | 56n | LQW15AN56NG00D | Murata Electronics | L_0402_1005Metric | 2 | 490-6830-1-ND | Cut Tape (CT) | 59 | $0.1200 | preferred |
| L302 L305 | 15n | LQW15AN15NJ00D | Murata Electronics | L_0402_1005Metric | 2 | 490-1148-1-ND | Cut Tape (CT) | 112566 | $0.1100 | preferred |
| L303 | 43n | LQW15AN43NG00D | Murata Electronics | L_0402_1005Metric | 1 | 490-6817-1-ND | Cut Tape (CT) | 15740 | $0.1200 | preferred |
| L304 | 22n | LQW15AN22NG00D | Murata Electronics | L_0402_1005Metric | 1 | 490-6787-1-ND | Cut Tape (CT) | 626141 | $0.1200 | preferred |
| L307 L308 | 27n | LQW15AN27NG00D | Murata Electronics | L_0402_1005Metric | 2 | 490-6792-1-ND | Cut Tape (CT) | 92890 | $0.1200 | preferred |
| L401 | 33n | LQW15AN33NG00D | Murata Electronics | L_0402_1005Metric | 1 | 490-6804-1-ND | Cut Tape (CT) | 42256 | $0.1200 | preferred |
| L402 | 4n3 | LQW15AN4N3C00D | Murata Electronics | L_0402_1005Metric | 1 | 490-1138-1-ND | Cut Tape (CT) | 24339 | $0.1100 | preferred |
| L403 | 4u7 | LQM18PN4R7MFRL | Murata Electronics | L_0603_1608Metric | 1 | 490-12065-1-ND | Cut Tape (CT) | 243007 | $0.1700 | preferred |
| L501 | 100u | 78F101J-RC | Bourns Inc. | L_Axial_D2.8mm_L7.2mm_P10.16mm_Horizontal | 1 | M10136-ND | Bulk | 10421 | $0.2200 | preferred |
| Q101 Q102 | DMG3401LSN-7 | DMG3401LSN-7 | Diodes Incorporated | SOT-23 | 2 | DMG3401LSN-7DICT-ND | Cut Tape (CT) | 152236 | $0.5600 | preferred |
| R101 R103 R104 | 100k | RC0402FR-07100KL | YAGEO | R_0402_1005Metric | 3 | 311-100KLRCT-ND | Cut Tape (CT) | 7885509 | $0.1000 | preferred |
| R102 R201 R401 R402 R403 R501 | 10k | RC0402FR-0710KL | YAGEO | R_0402_1005Metric | 6 | 311-10.0KLRCT-ND | Cut Tape (CT) | 14582185 | $0.1000 | preferred |
| R202 | 1k | RC0402FR-071KL | YAGEO | R_0402_1005Metric | 1 | 311-1.00KLRCT-ND | Cut Tape (CT) | 8230169 | $0.1000 | preferred |
| R203 R204 | 4k7 | RC0402FR-074K7L | YAGEO | R_0402_1005Metric | 2 | 311-4.7KLRCT-ND | Cut Tape (CT) | 1184846 | $0.1000 | preferred |
| R301 | 56k | RC0402FR-0756KL | YAGEO | R_0402_1005Metric | 1 | 311-56.0KLRCT-ND | Cut Tape (CT) | 716428 | $0.1000 | preferred |
| R302 | 18R | RC0402FR-0718RL | YAGEO | R_0402_1005Metric | 1 | YAG3021CT-ND | Cut Tape (CT) | 279481 | $0.1000 | preferred |
| R404 R405 | 0R | RC0402JR-070RL | YAGEO | R_0402_1005Metric | 2 | 311-0.0JRCT-ND | Cut Tape (CT) | 11522810 | $0.1000 | preferred |
| SW101 | PWR | JS102011SAQN | C&K | SW_SPDT_CK_JS102011SAQN | 1 | 401-1999-1-ND | Cut Tape (CT) | 57487 | $0.9000 | preferred |
| U201 | Wio-E5 | 114993120 | Seeed Technology Co., Ltd | WIO-E5 | 1 | 1597-114993120-ND | Box | 682 | $7.1100 | preferred |
| U301 | CC1200 | CC1200RHBR | Texas Instruments | Texas_RHB0032E_VQFN-32-1EP_5x5mm_P0.5mm_EP3.45x3.45mm | 1 | 296-38892-1-ND | Cut Tape (CT) | 5460 | $5.4300 | preferred |
| U401 | AT6558R-5N32 | AT6558R-5N32 |  | AT6558R_QFN-40-1EP_5x5mm_P0.4mm_EP3.4x3.4mm | 1 | - | - | - | - |  |
| U501 | SCD40-D-R2 | SCD40-D-R2 | Sensirion AG | Sensirion_SCD4x-1EP_10.1x10.1mm_P1.25mm_EP4.8x4.8mm | 1 | 1649-SCD40-D-R2CT-ND | Cut Tape (CT) | 3564 | $18.6600 | preferred |
| U502 | AS3935-BQFT | AS3935-BQFT | ScioSense | QFN-16-1EP_4x4mm_P0.65mm_EP2.7x2.7mm | 1 | AS3935-BQFTCT-ND | Cut Tape (CT) | 1426 | $9.3500 | preferred |
| U503 U504 | BME688 | BME688 | Bosch Sensortec | Bosch_LGA-8_3x3mm_P0.8mm_ClockwisePinNumbering | 2 | 828-BME688CT-ND | Cut Tape (CT) | 9011 | $8.9900 | preferred |
| X301 | 40MHz | CX3225SB40000D0FPLCC | KYOCERA AVX | Crystal_SMD_3225-4Pin_3.2x2.5mm | 1 | 478-CX3225SB40000D0FPLCCCT-ND | Cut Tape (CT) | 1614 | $0.8100 | preferred |
| X401 | TCXO 26MHz | UCF4031035LK005000-26MDK | Pletronics, Inc | Oscillator_SMD_ECS_2520MV-xxx-xx-4Pin_2.5x2.0mm | 1 | 4289-UCF4031035LK005000-26MDKCT-ND | Cut Tape (CT) | 249 | $3.0100 | preferred |
| X402 | 32.768kHz | FC3215AN 32.768K-C5NN60KC5 | EPSON | Crystal_SMD_3215-2Pin_3.2x1.5mm | 1 | 114-FC3215AN32.768K-C5NN60KC5CT-ND | Cut Tape (CT) | 2876 | $0.3900 | preferred |

## Substituted parts

The preferred part was out of stock or not orderable at this quantity, so the cheapest in-stock equivalent was taken instead.

- `GRM21BR61A226ME51L` -> `LMK212BBJ226MD-T` (22u, C101 C106 C502)
- `GRM155R61A105KE15D` -> `LMK105BJ105KVHF` (1u, C102 C202 C312 C402 C405 C409 C412 C417 C418 C419 C504 C511 C512 C513)
- `GRM188R60J106ME84D` -> `GRM188R60J106KE47D` (10u, C104 C203 C411 C503)
- `GRM155R71C104KA88D` -> `CL05B104KO5NNNC` (100n, C107 C201 C204 C403 C404 C406 C407 C408 C410 C413 C420 C421 C501 C507 C508 C509 C510 C514)
- `GRM1555C1H390JA01D` -> `CC0402JRNPO9BN390` (39p, C321)
- `GRM1555C1H5R1CA01D` -> `GJM1555C1H5R1CB01D` (5p1, C323 C325 C326)
- `GRM1555C1H6R2CA01D` -> `GJM1555C1H6R2BB01D` (6p2, C324)
- `GRM1555C1H911JA01D` -> `GCM1555C1H911FA16J` (910p, C505)
- `GRM1555C1H470JA01D` -> `CC0402JRNPO9BN470` (47p, C506)

## Not in digikey_bom.csv

DigiKey cannot fulfil these as uploaded, so they are left out of the upload rather than going in as blank lines. Order them separately or add them by hand.

- `GRM1555C1H100JA01D` (10p, C415 C416): do not populate - optional, DigiKey 490-5921-1-ND if you want it
- `FCS0V104ZFTBR24` (100m, C422): do not populate - optional, DigiKey 399-13093-1-ND if you want it
- `AT6558R-5N32` (AT6558R-5N32, U401): no DigiKey match; order from LCSC C500608 / JLCPCB

## Sourcing risks

Orderable, but not comfortably so. Stock is judged against the 8-board run, not the one board the CSV quantities are for.

- `BMV080` (BMV080, J501): Discontinued at DigiKey; pack of 10 (need 8)
- `LQW15AN56NG00D` (56n, L301 L306): only 59 in stock

## Needs attention

- `AT6558R-5N32` (AT6558R-5N32, U401): not stocked at DigiKey; order from LCSC C500608 / JLCPCB

Lines with no unit price at this quantity: `AT6558R-5N32`

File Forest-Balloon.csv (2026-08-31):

Country of Origin may be different at time of shipment.
The HTSUS and ECCN information shown is for informational purposes only and is not a representation or warranty as to the accuracy or reliability of these classifications. All information is provided "as is" and is subject to change without notice. Any use made of the information provided is without recourse to Digi-Key and at the user's risk.
Index | Manufacturer Part Number | Manufacturer Name | Description | Lead Time | Availability | Stock Status | Attrition % | Requested Quantity 1 | Pack Quantity 1 | Pack Type 1 | Digi-Key Part Number 1 | Unit Price 1 | Extended Price 1 | Minimum Order Quantity 1 | Customer Reference | Requested Part Number | Lead Weeks | Datasheet | Reference Designator | US Import Tariff | Note | Part Status | RoHS Status | REACH Status | Moisture Sensitivity Level (MSL) | ECCN | HTSUS | Country of Origin | Environmental Information | Original Part numbers | Unit of Measure | Image | Product Notes
1 | CC1200RHBR | Texas Instruments | IC RF TXRX+MCU ISM 1GHZ 32VQFN |  | 5,460 | In Stock |  | 1 | 1 | Cut Tape (CT) | 296-38892-1-ND | 5.43000 | $5.43 | 1 |  | 296-38892-1-ND | 16 | https://www.ti.com/general/docs/suppproductinfo.tsp?distId=10 |  | May apply on shipments to the U.S. |  | Active | ROHS3 Compliant | REACH Unaffected | 3 (168 Hours) | 5A992C | 8542.39.0010 | China |  | 296-38892-1-ND | Each | https://mm.digikey.com/Volume0/opasdata/d220001/derivates/6/003/249/251/MFG_296%7E4223442%7ERHB%7E32_web%28640x640%29.jpg
2 | SCD40-D-R2 | Sensirion AG | SENSOR AIR QUALITY I2C OUTPUT |  | 3,564 | In Stock |  | 1 | 1 | Cut Tape (CT) | 1649-SCD40-D-R2CT-ND | 18.66000 | $18.66 | 1 |  | 1649-SCD40-D-R2CT-ND | 12 | https://sensirion.com/media/documents/48C4B7FB/67FE0194/CD_DS_SCD4x_Datasheet_D1.pdf |  | - |  | Active | ROHS3 Compliant | REACH Unaffected | 1 (Unlimited) | EAR99 | 8541.51.0000 | Switzerland | https://www.sensirion.com/fileadmin/user_upload/customers/sensirion/Dokumente/3_Temperature_Sensors/Sensirion_REACH-RoHS-HalFree_Humidity-Temperature.pdf|https://sensirion.com/media/documents/F295B2F9/62D8FCE4/Sensirion_Prop-65.pdf | 1649-SCD40-D-R2CT-ND | Each | https://mm.digikey.com/Volume0/opasdata/d220001/medias/images/2671/MFG_SCD42-D-R2.jpg
3 | AS3935-BQFT | ScioSense | SENSOR LIGHTNING I2C SPI |  | 1,426 | In Stock |  | 1 | 1 | Cut Tape (CT) | AS3935-BQFTCT-ND | 9.35000 | $9.35 | 1 |  | AS3935-BQFTCT-ND | 4 | https://www.sciosense.com/AS3935-Datasheet |  | May apply on shipments to the U.S. |  | Active | RoHS Compliant | REACH Unaffected | 3 (168 Hours) | EAR99 | 8542.39.0070 | Austria |  | AS3935-BQFTCT-ND | Each | https://mm.digikey.com/Volume0/opasdata/d220001/medias/images/4845/961_16-QFN.jpg
4 | BMV080 | Bosch Sensortec | SENSOR PARTICLE MODULE 10 PCS |  | 610 | In Stock - Non-Stock |  | 1 | 10 | Box | 828-BMV080-10PC-ND | 37.86800 | $378.68 | 10 |  | 828-BMV080-10PC-ND | 8 | https://www.bosch-sensortec.com/media/boschsensortec/downloads/datasheets/bst-bmv080-ds000.pdf |  | May apply on shipments to the U.S. |  | Discontinued at Digi-Key | ROHS3 Compliant | REACH Unaffected | 1 (Unlimited) | EAR99 | 9027.10.4000 | China |  | 828-BMV080-10PC-ND | Each | https://mm.digikey.com/Volume0/opasdata/d220001/derivates/6/003/230/294/MFG_BMV080_web%28640x640%29.jpg | No Backorders Allowed.
5 | BME688 | Bosch Sensortec | SENSOR GAS/HUM/PRES/TEMP I2C SPI |  | 9,052 | In Stock |  | 1 | 1 | Cut Tape (CT) | 828-BME688CT-ND | 8.99000 | $8.99 | 1 |  | 828-BME688CT-ND | 12 | https://www.bosch-sensortec.com/media/boschsensortec/downloads/datasheets/bst-bme688-ds000.pdf |  | May apply on shipments to the U.S. |  | Active | ROHS3 Compliant | REACH Unaffected | 1 (Unlimited) | EAR99 | 8542.39.0090 | Philippines |  | 828-BME688CT-ND | Each | https://mm.digikey.com/Volume0/opasdata/d220001/medias/images/4544/MFG_BME688.JPG
6 | BME688 | Bosch Sensortec | SENSOR GAS/HUM/PRES/TEMP I2C SPI |  | 9,052 | In Stock |  | 1 | 1 | Cut Tape (CT) | 828-BME688CT-ND | 8.99000 | $8.99 | 1 |  | 828-BME688CT-ND | 12 | https://www.bosch-sensortec.com/media/boschsensortec/downloads/datasheets/bst-bme688-ds000.pdf |  | May apply on shipments to the U.S. |  | Active | ROHS3 Compliant | REACH Unaffected | 1 (Unlimited) | EAR99 | 8542.39.0090 | Philippines |  | 828-BME688CT-ND | Each | https://mm.digikey.com/Volume0/opasdata/d220001/medias/images/4544/MFG_BME688.JPG

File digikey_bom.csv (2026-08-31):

Quantity | Digi-Key Part Number | Customer Reference
3 | 587-5917-1-ND | C101 C106 C502
14 | 587-3712-1-ND | 1u 0402 x14
4 | 490-12538-1-ND | C104 C203 C411 C503
18 | 1276-1001-1-ND | 100n 0402 x18
11 | 490-10702-1-ND | 47n 0402 x11
2 | 490-5922-1-ND | C310 C414
2 | 490-4516-1-ND | C311 C314
1 | 1276-1455-1-ND | C313
1 | 490-GRM1555C1H182JA01DCT-ND | C317
2 | 1276-1178-1-ND | C318 C319
1 | 490-1288-1-ND | C320
1 | 311-1009-1-ND | C321
1 | 490-5932-1-ND | C322
3 | 490-3102-1-ND | C323 C325 C326
1 | 490-11231-1-ND | C324
1 | 490-1297-1-ND | C401
1 | 490-GCM1555C1H911FA16JCT-ND | C505
1 | 311-1021-1-ND | C506
1 | SMF6.5A-TPMSCT-ND | D101
1 | 160-1446-1-ND | D201
1 | 535-AANI-AP-0158-1-ND | J401
1 | 478-046844713002846+CT-ND | J501
1 | 828-BMV080-10PC-ND | J501
2 | 490-6830-1-ND | L301 L306
2 | 490-1148-1-ND | L302 L305
1 | 490-6817-1-ND | L303
1 | 490-6787-1-ND | L304
2 | 490-6792-1-ND | L307 L308
1 | 490-6804-1-ND | L401
1 | 490-1138-1-ND | L402
1 | 490-12065-1-ND | L403
1 | M10136-ND | L501
2 | DMG3401LSN-7DICT-ND | Q101 Q102
3 | 311-100KLRCT-ND | R101 R103 R104
6 | 311-10.0KLRCT-ND | R102 R201 R401 R402 R403 R501
1 | 311-1.00KLRCT-ND | R202
2 | 311-4.7KLRCT-ND | R203 R204
1 | 311-56.0KLRCT-ND | R301
1 | YAG3021CT-ND | R302
2 | 311-0.0JRCT-ND | R404 R405
1 | 401-1999-1-ND | SW101
1 | 1597-114993120-ND | U201
1 | 296-38892-1-ND | U301
1 | 1649-SCD40-D-R2CT-ND | U501
1 | AS3935-BQFTCT-ND | U502
2 | 828-BME688CT-ND | U503 U504
1 | 478-CX3225SB40000D0FPLCCCT-ND | X301
1 | 4289-UCF4031035LK005000-26MDKCT-ND | X401
1 | 114-FC3215AN32.768K-C5NN60KC5CT-ND | X402

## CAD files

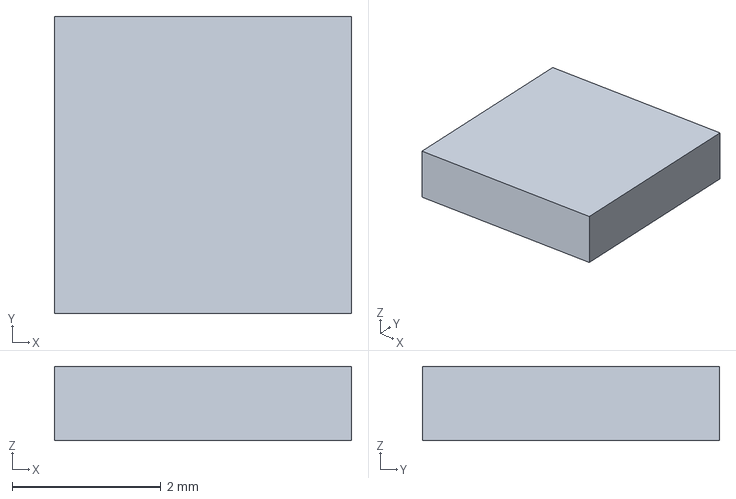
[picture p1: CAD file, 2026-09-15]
models/AS3935-BQFT-Extrude.step
4.00 x 4.00 x 1.00 mm

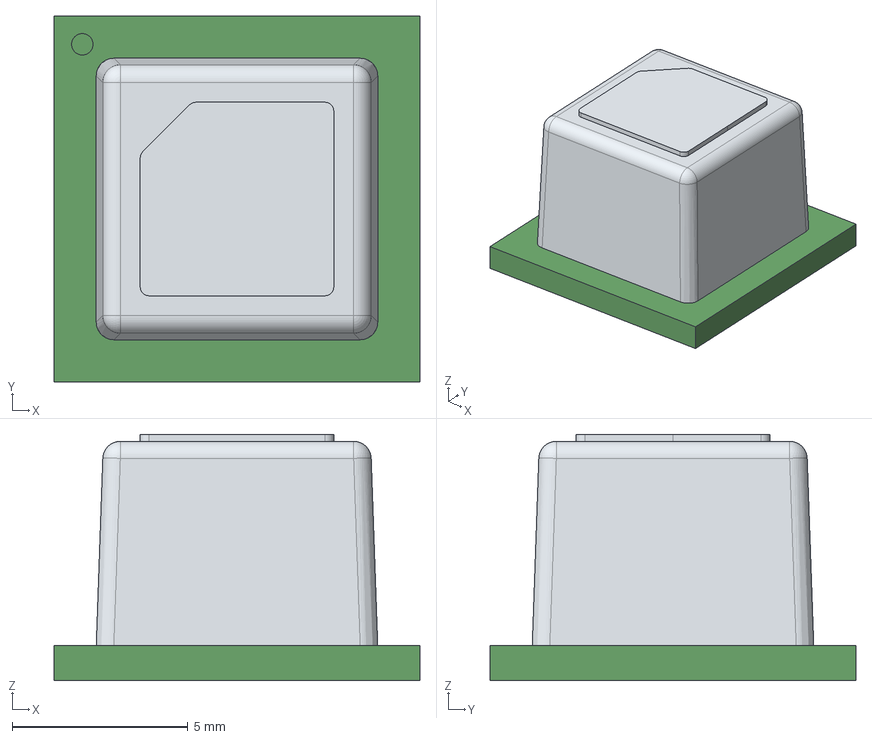
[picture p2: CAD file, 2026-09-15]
models/SCD40.step
10.4 x 10.4 x 7.00 mm

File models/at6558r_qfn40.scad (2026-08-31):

// ZHONGKEWEI AT6558R-5N32: QFN-40, 5 x 5 x 0.8 mm.
//
// Perimeter only - the 40 side terminals and the exposed pad are not
// modelled. Authored in KiCad 3D model space (Y is the footprint's Y
// negated, Z is height above the board).

$fn = 32;

BODY = 5.0;
HEIGHT = 0.8;
STANDOFF = 0.05;
PIN1_R = 0.6;   // dimple over pin 1, footprint (-2.44, -1.8)

module qfn40() {
    difference() {
        translate([-BODY / 2, -BODY / 2, STANDOFF])
            cube([BODY, BODY, HEIGHT]);
        translate([-1.7, 1.7, STANDOFF + HEIGHT - 0.15])
            cylinder(r = PIN1_R, h = 0.3);
    }
}

qfn40();

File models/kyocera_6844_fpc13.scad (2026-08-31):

// KYOCERA AVX 046844713002846+: 0.3 mm pitch, 13 position, right-angle
// bottom-contact FPC/ZIF connector. Mates the Bosch BMV080 flex.
//
// Perimeter only - the housing block plus the flip-lock actuator as one
// slab each; contacts, latch detail and the FPC itself are not modelled.
// Authored in KiCad 3D model space (Y is the footprint's Y negated, Z is
// height above the board).

$fn = 24;

WIDTH = 5.5;      // B column of the series drawing at 13 positions
DEPTH = 4.0;
HEIGHT = 0.95;    // mated height
ACT_DEPTH = 1.2;  // flip-lock actuator, shown closed

module housing() {
    translate([-WIDTH / 2, -DEPTH / 2, 0])
        cube([WIDTH, DEPTH - ACT_DEPTH, HEIGHT]);
}

module actuator() {
    translate([-WIDTH / 2, DEPTH / 2 - ACT_DEPTH, HEIGHT - 0.35])
        cube([WIDTH, ACT_DEPTH, 0.35]);
}

housing();
actuator();

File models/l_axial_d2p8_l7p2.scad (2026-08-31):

// Bourns 78F101J-RC, 100 uH axial drum-core choke used as the AS3935
// 500 kHz antenna. Body 2.79 mm diameter x 7.11 mm long, 0.5 mm leads,
// lying flat on a 10.16 mm lead pitch.
//
// Perimeter only - the winding, the end caps and the lead bends are a
// single cylinder plus straight wires. Authored in KiCad 3D model space.

$fn = 32;

BODY_D = 2.8;
BODY_L = 7.2;
LEAD_D = 0.5;
PITCH = 10.16;
AXIS_Z = BODY_D / 2 + 0.2;   // 0.2 mm standoff off the board

module body() {
    translate([-BODY_L / 2, 0, AXIS_Z])
        rotate([0, 90, 0])
            cylinder(d = BODY_D, h = BODY_L);
}

module lead(sign) {
    // horizontal run from the body end out to the lead hole
    translate([sign * BODY_L / 2, 0, AXIS_Z])
        rotate([0, sign * 90, 0])
            cylinder(d = LEAD_D, h = PITCH / 2 - BODY_L / 2);
    // vertical drop into the board
    translate([sign * PITCH / 2, 0, -1.6])
        cylinder(d = LEAD_D, h = AXIS_Z + 1.6);
}

body();
lead(1);
lead(-1);

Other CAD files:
models/supercap_kemet_fcs.scad
models/wio_e5.scad

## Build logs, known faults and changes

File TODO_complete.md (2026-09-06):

# Completed

## 2026-09-06 - Rewire the GNSS to the real AT6558R-5N32 pinout

The receiver had been wired from an invented pinout. Pin names the part does
not have (`VANT_IN`, `VDD_POR`, `BBLDO_OUT`, `VDX`, `AVDD`), numbers to
match, and comments citing data sheet sections that do not exist. **Not one
of the 40 pins was on the right pad.** Every gate in `build.sh` passed the
whole time, because every gate compares the design to `sheets/gnss.json` and
that file was the thing that was wrong.

Rebuilt against `ref/AT6558R-5N32.pdf` (`DS-AT6558-R` v1.0), section 2.2.

- `sheets/gnss.json` rewritten to the section 3.2.1 low-power supply scheme:
  `+BATT` into `VDD_IO` (7) and `DX_IN` (21); `DX_OUT` (22) through `L403`
  4.7 uH into `VCORE` (23); 1 uF on each of the five internal LDO outputs;
  `VX_OUT` (2) powering the TCXO and its enable.
- UART0 is the NMEA port per section 7.1 - `GPIO0/TXD0` (19) and
  `GPIO1/RXD0` (18) through 22R series, replacing 10k series resistors that
  were on the wrong pins anyway. 1PPS moved to `GPIO13` (35).
- Antenna bias-T to the section 8.1 values: `L401` 33 nH choke, `C401`
  100 nF, `C402` 100 pF DC block, `L402` 6.8 nH series match.
- `nRST` (17) left floating as section 2.2 requires, instead of tied to the
  board reset net. `ON_OFF` (30) keeps MCU sleep control.
- Dropped `C415`/`C416` (RTC crystal load caps): section 9.5 is explicit
  that the crystal takes none. Dropped `R404`, `R405`; renumbered the
  supercapacitor `C422` -> `C414`, now wired straight to `VDD_BK`.
- Net count on the sheet went 15 -> 26 components, all 41 pads accounted
  for: 24 on nets, 17 explicitly no-connect.

`tools/gen_symbols.ts` - AT6558R symbol redrawn to the data sheet table and
to one rule set: supplies on the top edge and ground on the bottom, both in
pin-number order; signals on the sides in functional groups separated by a
blank slot, pin-number order within each group. Added `groupLadder()` for
the grouped spacing. Symbol now points at the project footprint instead of a
stock QFN.

`tools/gen_footprints.ts` - `AT6558R_QFN-40-1EP_5x5mm_P0.4mm_EP3.4x3.4mm`
generated from the section 10.2 package drawing instead of patched from a
stock KiCad file. The patched version left the nine paste apertures laid out
for a 3.6 mm land on the 3.4 mm one: 73% coverage ending 0.015 mm from the
edge. Now 3 x 3 of 0.9 mm on a 1.15 mm pitch, 63% coverage, 0.1 mm clear.
Added `polyline()`, `poly()` and pad layer/extra overrides to support it.

`tools/gen_bom.ts` - added 22R 0402, 4.7 uF 0603 and 6.8 nH 0402 generics;
`33n` moved to the data sheet's own LQW15AN33NH00D.

GNSS sheet dropped from A1 to A3 - the content is 319 x 158 mm.

Docs: `README.md` architecture diagram, antenna and RTC-backup sections,
verification counts, and a new limitation (the AT6558R is out of spec below
2.7 V, so it quits before the rest of the board). `NOTES.md` AT6558R and
supercapacitor sections rewritten, with a Gantt of the section 3.4 power-up
sequence and a table of the data sheet's self-contradicting inductor BOM.

Gates: placement 5/5, routing DRC 0, netlist matches `sheets/*.json` at 352
endpoints / 74 nets, full-hierarchy ERC 0 errors and the 2 known BME688
address-strap warnings, `bun test` 10/10.

### Still open

- `cc1200_balloon.kicad_pcb` has 10 orphan footprints (`C415`-`C422`,
  `R404`, `R405`) and no net table at all. It needs "Update PCB from
  Schematic" in the GUI, which does the adds, removes and net assignment in
  one pass.
- `BOM.md` and `digikey_bom.csv` are stale: only `tools/source_bom.py`
  writes them and its interpreter is not installed here. `bom.json` is
  current.

## 2026-09-05 - Demote sheet-local global labels

- Added `tools/localize.ts`: any global label that is not a declared
  inter-sheet net, does not name a power symbol, and appears on exactly one
  sheet becomes a plain local label. Runs after `assemble.ts`.
- Demoted 40 labels over 31 nets: 4 on MCU (SWDIO, SWCLK, STATUS_LED,
  DBG_TX), 8 on the radio sheet (XOSC_Q1/Q2, RF_PA, RF_LNAP, RF_LNAN,
  RF_TRXSW, RADIO_GPIO0/3), 28 on GNSS (the AT6558R internal supply and
  test pins). Power and Sensors had none to demote.
- `+BATT` on the radio sheet stayed global: it names a power symbol, and a
  local label of that name would split off the rail without an ERC error.
- Extended `tools/checkglobals.ts` to fail on a single-sheet global label
  as well as on an undeclared multi-sheet one, so the demotion cannot
  regress.
- Extended `tools/fixlabels.ts` to normalize local label justification too,
  since flow-wire can rotate a label without updating it.
- Updated the `README.md` pipeline diagram and `build.sh`.

Verified by netlist partition compare: 96 nets before and after with
identical pin membership, 30 net names gained a sheet prefix, ERC output
unchanged.

## 2026-08-30 - Remove the buck-boost, run straight off the cell

- Deleted `U101` TPS63001 and `L101` 2.2 uH from `sheets/power.json`.
- Deleted `R102`/`C103` (converter VINA filter) and `C102`/`C105`
  (converter input/output bulk); kept `C101` 22u at the entry and
  `C104` 10u + `C106` 22u on the rail.
- Renamed the rail `+3V3` -> `+BATT` across all five sheets. Updated
  `tools/fixflags.ts` (`+BATT` is now a shared, passively driven rail that
  needs one PWR_FLAG on the power sheet) and the root title block in
  `tools/assemble.ts`.
- Added `Q102`, a second DMG3401LSN-7 back to back with `Q101`, so `SW101`
  switches the load instead of a regulator enable pin.
- Re-used the freed `R102`/`C102` designators as a 10k/1u gate network for
  about 9 ms of soft start, replacing the converter's.
- Moved the `R103`/`R104` sense divider from `VBATT` to the switched
  `+BATT`, so it draws nothing with the switch off.
- Updated `README.md` (new Power section, architecture diagram, verification
  counts) and `NOTES.md`.

Gates after the change: placement 5/5, routing DRC 0, netlist matches
`sheets/*.json` at 378 endpoints / 76 nets, full-hierarchy ERC 0 errors and
the 2 known BME688 address-strap warnings.

### Found on the way

- `tools/assemble.ts` rewrote `cc1200_balloon.kicad_pro` from a fixed
  template on every build, wiping the net classes, board design settings and
  ERC severities KiCad had written. It now merges the template into an
  existing file and leaves a complete one untouched.

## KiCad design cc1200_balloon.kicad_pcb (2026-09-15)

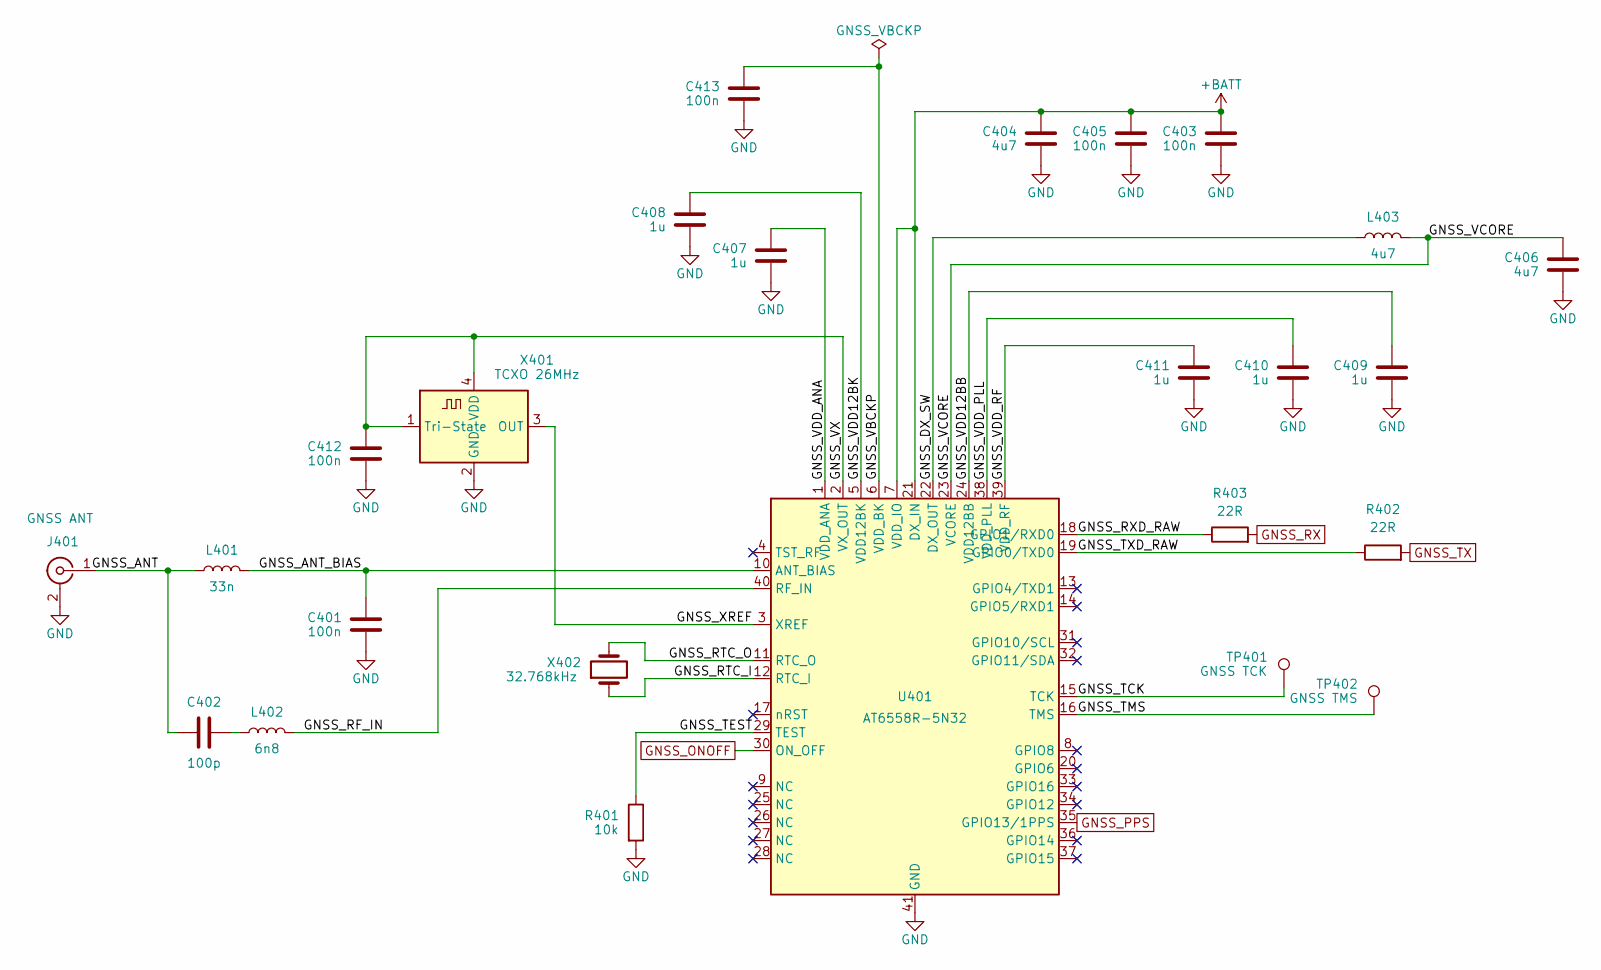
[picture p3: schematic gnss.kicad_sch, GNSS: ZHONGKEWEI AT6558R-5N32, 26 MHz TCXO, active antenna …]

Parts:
C401, C403, C405, C412, C413: 100n; C_0402_1005Metric
C402: 100p; C_0402_1005Metric
C404, C406: 4u7; C_0603_1608Metric
C407, C408, C409, C410, C411: 1u; C_0402_1005Metric
J401: GNSS ANT; SMA_Samtec_SMA-J-P-H-ST-EM1_EdgeMount
L401: 33n; L_0402_1005Metric
L402: 6n8; L_0402_1005Metric
L403: 4u7; L_0603_1608Metric; MPN LQM18PN4R7MFRL
R401: 10k; R_0402_1005Metric
R402, R403: 22R; R_0402_1005Metric
TP401: GNSS TCK; TestPoint_Pad_1.0x1.0mm
TP402: GNSS TMS; TestPoint_Pad_1.0x1.0mm
U401: AT6558R-5N32; AT6558R_QFN-40-1EP_5x5mm_P0.4mm_EP3.4x3.4mm; MPN AT6558R-5N32
X401: TCXO 26MHz; Oscillator_SMD_ECS_2520MV-xxx-xx-4Pin_2.5x2.0mm; MPN KT2520K26000ACW33T
X402: 32.768kHz; Crystal_SMD_3215-2Pin_3.2x1.5mm; MPN FC-135 32.768KA-A5

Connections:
+BATT: C403.1, C404.1, C405.1, U401.7 (VDD_IO), U401.21 (DX_IN); also elsewhere on the board
/GNSS/GNSS_ANT: C402.1, J401.1 (In), L401.1
/GNSS/GNSS_ANT_BIAS: C401.1, L401.2, U401.10 (ANT_BIAS)
/GNSS/GNSS_DX_SW: L403.1, U401.22 (DX_OUT)
/GNSS/GNSS_RF_IN: L402.2, U401.40 (RF_IN)
/GNSS/GNSS_RTC_I: U401.12 (RTC_I), X402.1
/GNSS/GNSS_RTC_O: U401.11 (RTC_O), X402.2
/GNSS/GNSS_RXD_RAW: R403.1, U401.18 (GPIO1/RXD0)
/GNSS/GNSS_TCK: TP401.1 (1_1), U401.15 (TCK)
/GNSS/GNSS_TEST: R401.1, U401.29 (TEST)
/GNSS/GNSS_TMS: TP402.1 (1_1), U401.16 (TMS)
/GNSS/GNSS_TXD_RAW: R402.1, U401.19 (GPIO0/TXD0)
/GNSS/GNSS_VBCKP: C413.1, U401.6 (VDD_BK)
/GNSS/GNSS_VCORE: C406.1, L403.2, U401.23 (VCORE)
/GNSS/GNSS_VDD12BB: C409.1, U401.24 (VDD12BB)
/GNSS/GNSS_VDD12BK: C408.1, U401.5 (VDD12BK)
/GNSS/GNSS_VDD_ANA: C407.1, U401.1 (VDD_ANA)
/GNSS/GNSS_VDD_PLL: C410.1, U401.38 (VDD_PLL)
/GNSS/GNSS_VDD_RF: C411.1, U401.39 (VDD_RF)
/GNSS/GNSS_VX: C412.1, U401.2 (VX_OUT), X401.1 (Tri-State), X401.4 (VDD)
/GNSS/GNSS_XREF: U401.3 (XREF), X401.3 (OUT)
GND: C401.2, C403.2, C404.2, C405.2, C406.2, C407.2, C408.2, C409.2, C410.2, C411.2, C412.2, C413.2, J401.2 (Ext), R401.2, U401.41 (GND), X401.2 (GND); also elsewhere on the board
GNSS_ONOFF: U401.30 (ON_OFF); also elsewhere on the board
GNSS_PPS: U401.35 (GPIO13/1PPS); also elsewhere on the board
GNSS_RX: R403.2; also elsewhere on the board
GNSS_TX: R402.2; also elsewhere on the board
unnamed: C402.2, L402.1

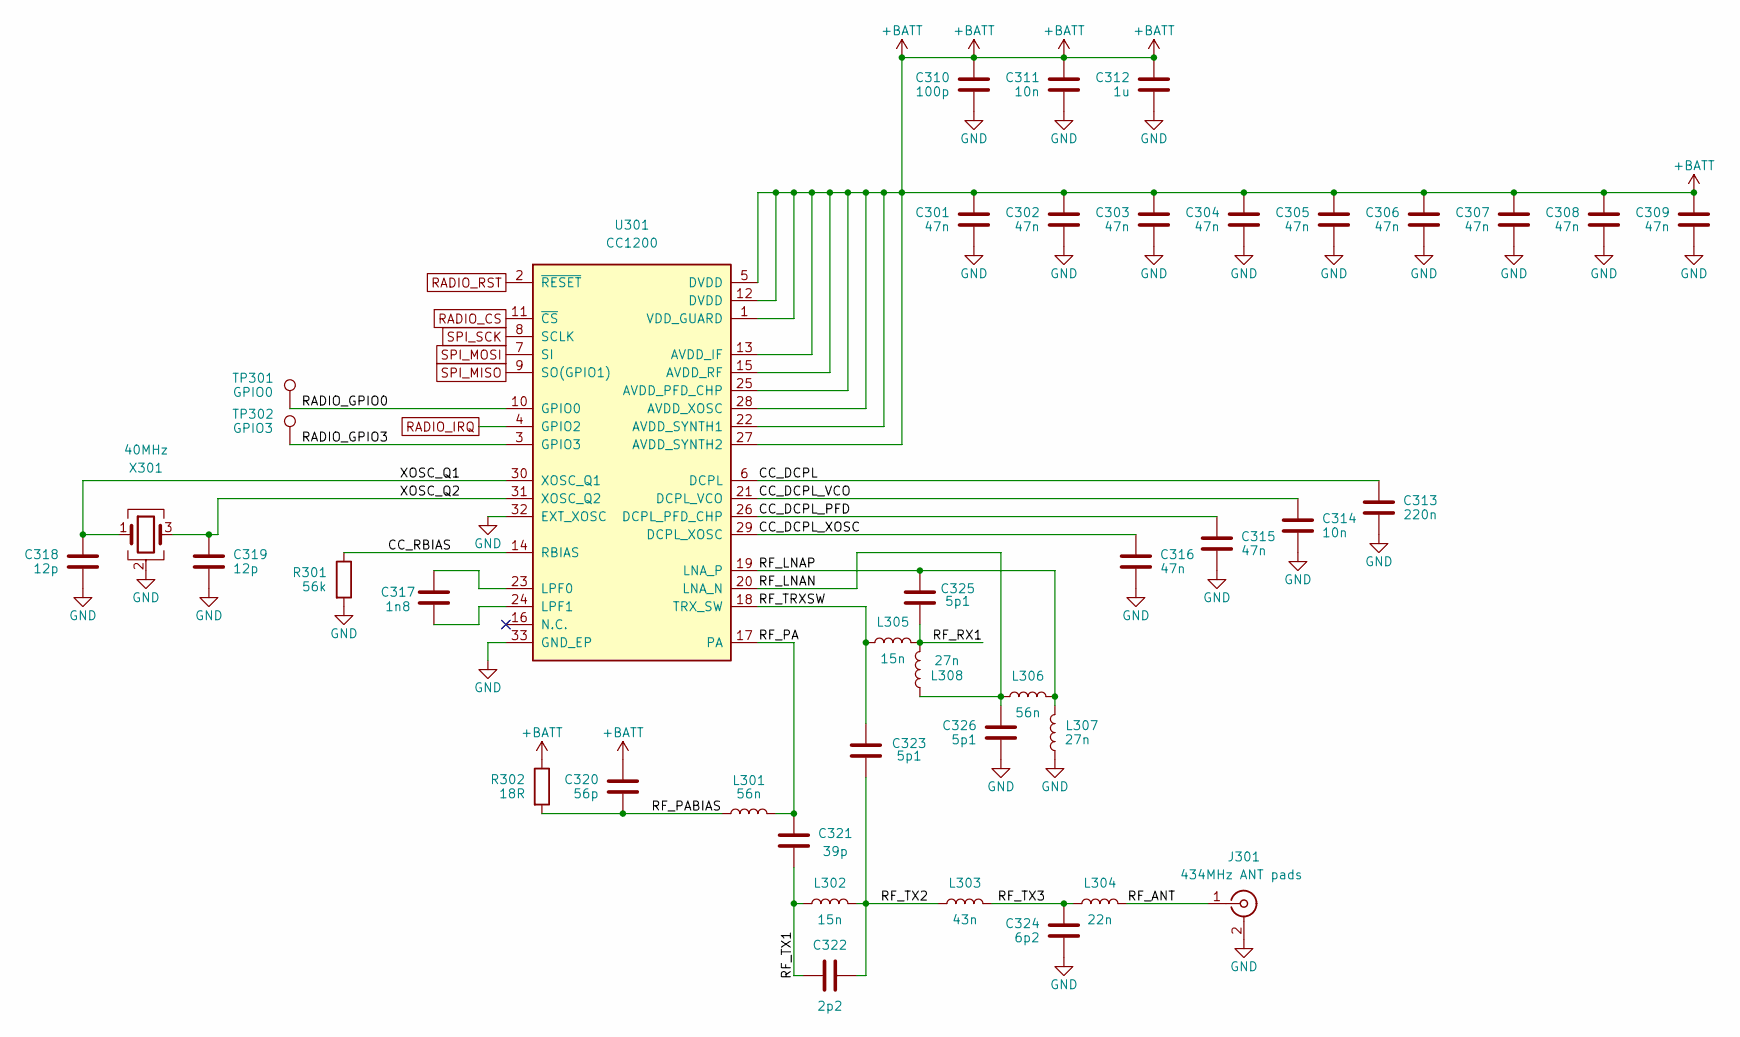
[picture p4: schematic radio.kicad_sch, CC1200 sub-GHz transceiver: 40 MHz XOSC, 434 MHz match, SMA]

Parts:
C301, C302, C303, C304, C305, C306, C307, C308, C309, C315, C316: 47n; C_0402_1005Metric
C310: 100p; C_0402_1005Metric
C311, C314: 10n; C_0402_1005Metric
C312: 1u; C_0402_1005Metric
C313: 220n; C_0402_1005Metric
C317: 1n8; C_0402_1005Metric
C318, C319: 12p; C_0402_1005Metric
C320: 56p; C_0402_1005Metric
C321: 39p; C_0402_1005Metric
C322: 2p2; C_0402_1005Metric
C323, C325, C326: 5p1; C_0402_1005Metric
C324: 6p2; C_0402_1005Metric
J301: 434MHz ANT pads; SMA_Samtec_SMA-J-P-H-ST-EM1_EdgeMount
L301, L306: 56n; L_0402_1005Metric
L302, L305: 15n; L_0402_1005Metric
L303: 43n; L_0402_1005Metric
L304: 22n; L_0402_1005Metric
L307, L308: 27n; L_0402_1005Metric
R301: 56k; R_0402_1005Metric
R302: 18R; R_0402_1005Metric
TP301: GPIO0; TestPoint_Pad_1.0x1.0mm
TP302: GPIO3; TestPoint_Pad_1.0x1.0mm
U301: CC1200; Texas_RHB0032E_VQFN-32-1EP_5x5mm_P0.5mm_EP3.45x3.45mm; MPN CC1200RHBR
X301: 40MHz; Crystal_SMD_3225-4Pin_3.2x2.5mm; MPN CX3225SB40000D0FPLCC

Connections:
+BATT: C301.1, C302.1, C303.1, C304.1, C305.1, C306.1, C307.1, C308.1, C309.1, C310.1, C311.1, C312.1, C320.1, R302.1, U301.1 (VDD_GUARD), U301.5 (DVDD), U301.12 (DVDD), U301.13 (AVDD_IF), U301.15 (AVDD_RF), U301.22 (AVDD_SYNTH1), U301.25 (AVDD_PFD_CHP), U301.27 (AVDD_SYNTH2), U301.28 (AVDD_XOSC); also elsewhere on the board
/CC1200 Radio/CC_DCPL: C313.1, U301.6 (DCPL)
/CC1200 Radio/CC_DCPL_PFD: C315.1, U301.26 (DCPL_PFD_CHP)
/CC1200 Radio/CC_DCPL_VCO: C314.1, U301.21 (DCPL_VCO)
/CC1200 Radio/CC_DCPL_XOSC: C316.1, U301.29 (DCPL_XOSC)
/CC1200 Radio/CC_RBIAS: R301.1, U301.14 (RBIAS)
/CC1200 Radio/RADIO_GPIO0: TP301.1 (1_1), U301.10 (GPIO0)
/CC1200 Radio/RADIO_GPIO3: TP302.1 (1_1), U301.3 (GPIO3)
/CC1200 Radio/RF_ANT: J301.1 (In), L304.2
/CC1200 Radio/RF_LNAN: C326.1, L306.2, L308.1, U301.20 (LNA_N)
/CC1200 Radio/RF_LNAP: C325.2, L306.1, L307.1, U301.19 (LNA_P)
/CC1200 Radio/RF_PA: C321.2, L301.2, U301.17 (PA)
/CC1200 Radio/RF_PABIAS: C320.2, L301.1, R302.2
/CC1200 Radio/RF_RX1: C325.1, L305.2, L308.2
/CC1200 Radio/RF_TRXSW: C323.2, L305.1, U301.18 (TRX_SW)
/CC1200 Radio/RF_TX1: C321.1, C322.1, L302.1
/CC1200 Radio/RF_TX2: C322.2, C323.1, L302.2, L303.1
/CC1200 Radio/RF_TX3: C324.2, L303.2, L304.1
/CC1200 Radio/XOSC_Q1: C318.1, U301.30 (XOSC_Q1), X301.1
/CC1200 Radio/XOSC_Q2: C319.1, U301.31 (XOSC_Q2), X301.3
GND: C301.2, C302.2, C303.2, C304.2, C305.2, C306.2, C307.2, C308.2, C309.2, C310.2, C311.2, C312.2, C313.2, C314.2, C315.2, C316.2, C318.2, C319.2, C324.1, C326.2, J301.2 (Ext), L307.2, R301.2, U301.32 (EXT_XOSC), U301.33 (GND_EP), X301.2 (G), X301.4 (G); also elsewhere on the board
unnamed: C317.2, U301.23 (LPF0)
unnamed: C317.1, U301.24 (LPF1)
RADIO_CS: U301.11 (~CS); also elsewhere on the board
RADIO_IRQ: U301.4 (GPIO2); also elsewhere on the board
RADIO_RST: U301.2 (~RESET); also elsewhere on the board
SPI_MISO: U301.9 (SO(GPIO1)); also elsewhere on the board
SPI_MOSI: U301.7 (SI); also elsewhere on the board
SPI_SCK: U301.8 (SCLK); also elsewhere on the board

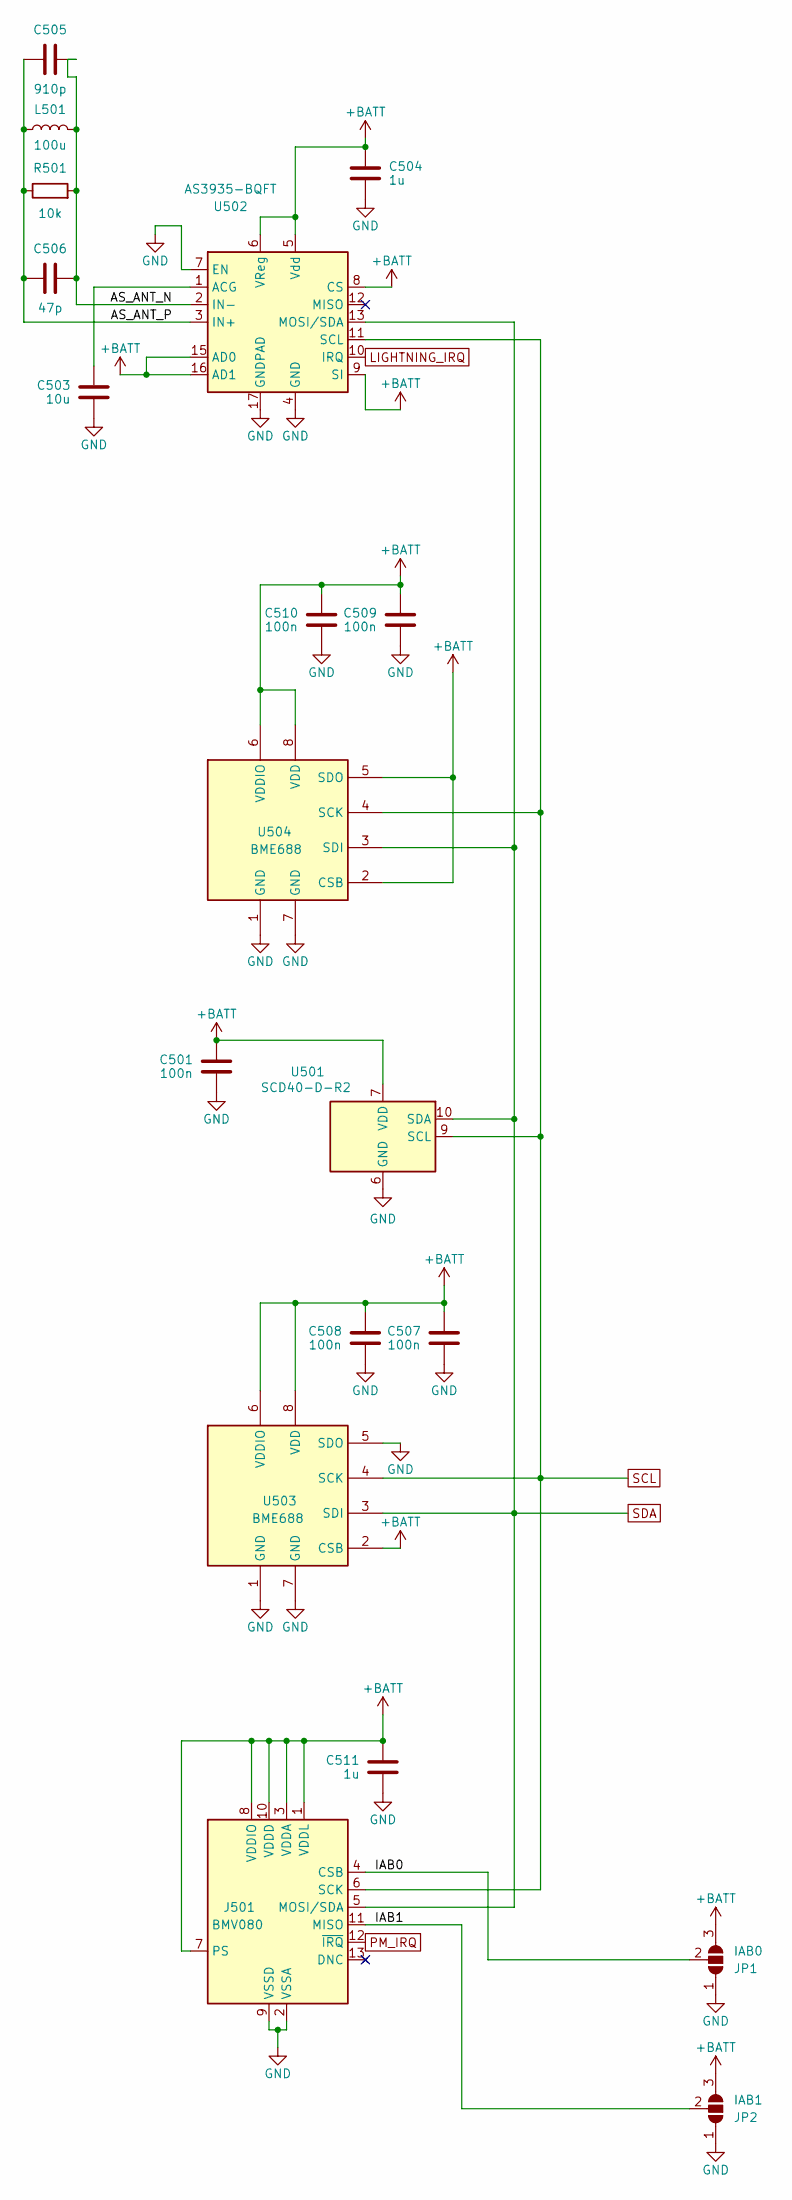
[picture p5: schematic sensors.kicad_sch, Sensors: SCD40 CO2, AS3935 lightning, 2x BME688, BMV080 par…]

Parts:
C501, C507, C508, C509, C510: 100n; C_0402_1005Metric
C503: 10u; C_0603_1608Metric
C504, C511: 1u; C_0402_1005Metric
C505: 910p; C_0402_1005Metric
C506: 47p; C_0402_1005Metric
J501: BMV080; Kyocera_046844713002846_FPC-13_P0.30mm; MPN 046844713002846+
JP1: IAB0; Jumper_3_0402
JP2: IAB1; Jumper_3_0402
L501: 100u; L_Axial_D2.8mm_L7.2mm_P10.16mm_Horizontal; MPN 78F101J-RC
R501: 10k; R_0402_1005Metric
U501: SCD40-D-R2; Sensirion_SCD4x-1EP_10.1x10.1mm_P1.25mm_EP4.8x4.8mm; MPN SCD40-D-R2
U502: AS3935-BQFT; QFN-16-1EP_4x4mm_P0.65mm_EP2.7x2.7mm; MPN AS3935-BQFT
U503, U504: BME688; Bosch_LGA-8_3x3mm_P0.8mm_ClockwisePinNumbering; MPN BME688

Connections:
+BATT: C501.1, C504.1, C507.1, C508.1, C509.1, C510.1, C511.1, J501.1 (VDDL), J501.3 (VDDA), J501.7 (PS), J501.8 (VDDIO), J501.10 (VDDD), JP1.3 (B), JP2.3 (B), U501.7 (VDD), U501.19 (VDD), U502.5 (Vdd), U502.6 (VReg), U502.8 (CS), U502.9 (SI), U502.15 (AD0), U502.16 (AD1), U503.2 (CSB), U503.6 (VDDIO), U503.8 (VDD), U504.2 (CSB), U504.5 (SDO), U504.6 (VDDIO), U504.8 (VDD); also elsewhere on the board
/Sensors/AS_ANT_N: C505.2, C506.2, L501.2, R501.2, U502.2 (IN-)
/Sensors/AS_ANT_P: C505.1, C506.1, L501.1, R501.1, U502.3 (IN+)
/Sensors/IAB0: J501.4 (CSB), JP1.2 (C)
/Sensors/IAB1: J501.11 (MISO), JP2.2 (C)
GND: C501.2, C503.2, C504.2, C507.2, C508.2, C509.2, C510.2, C511.2, J501.2 (VSSA), J501.9 (VSSD), JP1.1 (A), JP2.1 (A), U501.6 (GND), U501.20 (GND), U501.21 (GND), U502.4 (GND), U502.7 (EN), U502.17 (GNDPAD), U503.1 (GND), U503.5 (SDO), U503.7 (GND), U504.1 (GND), U504.7 (GND); also elsewhere on the board
LIGHTNING_IRQ: U502.10 (IRQ); also elsewhere on the board
unnamed: C503.1, U502.1 (ACG)
PM_IRQ: J501.12 (~IRQ); also elsewhere on the board
SCL: J501.6 (SCK), U501.9 (SCL), U502.11 (SCL), U503.4 (SCK), U504.4 (SCK); also elsewhere on the board
SDA: J501.5 (MOSI/SDA), U501.10 (SDA), U502.13 (MOSI/SDA), U503.3 (SDI), U504.3 (SDI); also elsewhere on the board

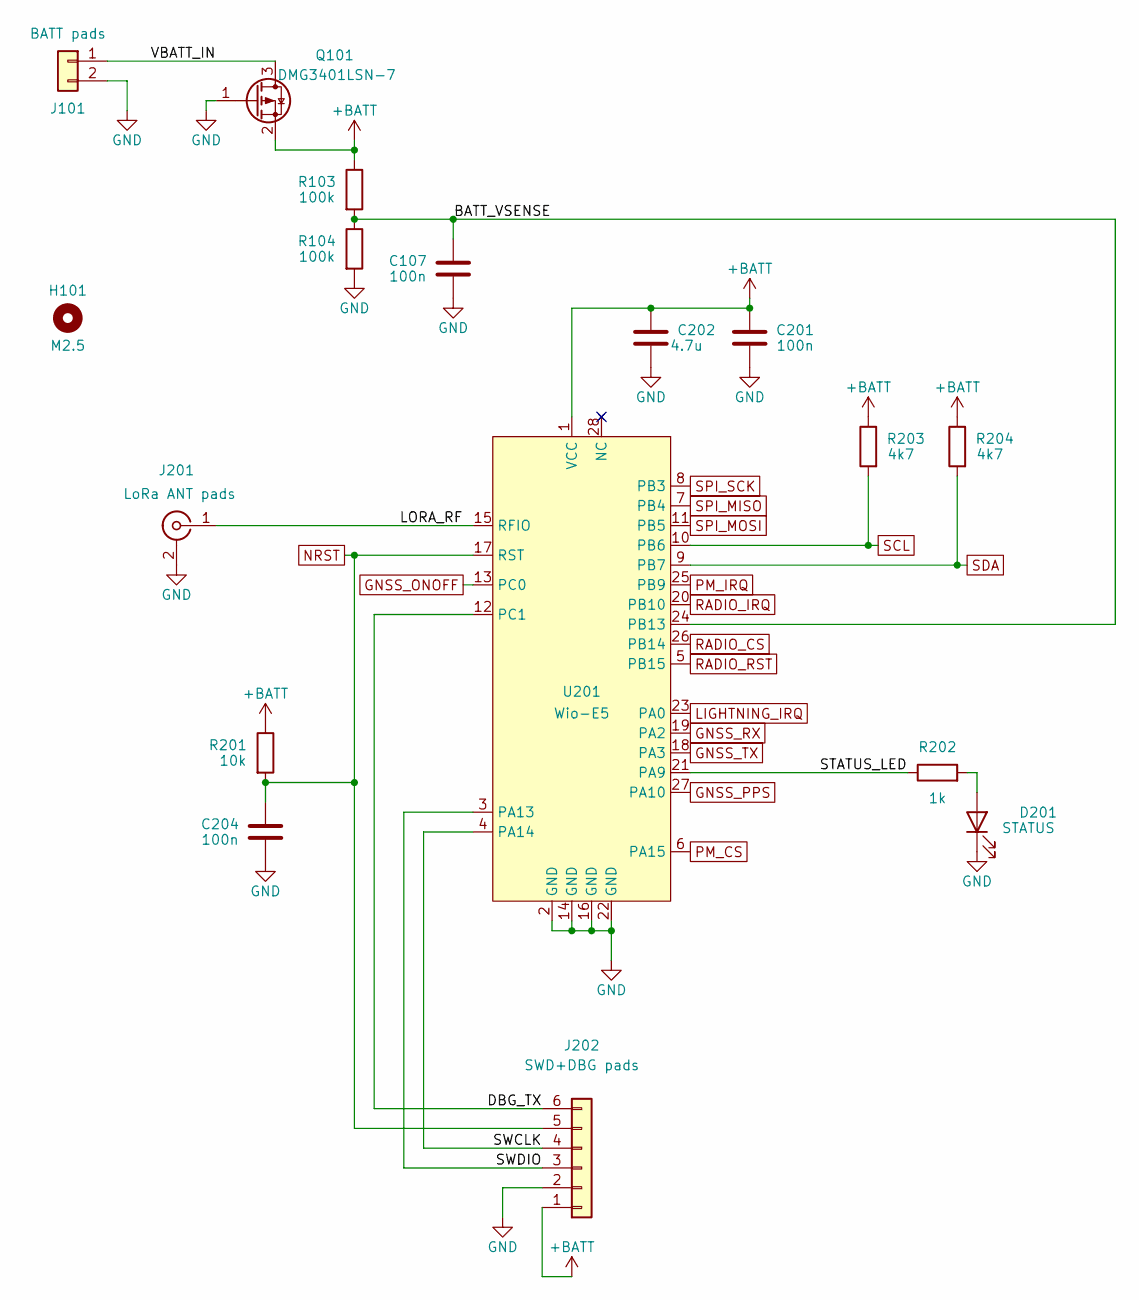
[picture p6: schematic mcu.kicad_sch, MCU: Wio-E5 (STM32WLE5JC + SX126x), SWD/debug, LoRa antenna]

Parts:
C107, C201, C204: 100n; C_0402_1005Metric
C202: 4.7u; C_0402_1005Metric
D201: STATUS; LED_0402_1005Metric
H101: M2.5; MountingHole_2.7mm_M2.5_ISO7380
J101: BATT pads; SolderPad_Wire_1x02_P3.0mm
J201: LoRa ANT pads; SMA_Samtec_SMA-J-P-H-ST-EM1_EdgeMount
J202: SWD+DBG pads; SolderPad_1x06_P1.27mm
Q101: DMG3401LSN-7; SOT-23; MPN DMG3401LSN-7
R103, R104: 100k; R_0402_1005Metric
R201: 10k; R_0402_1005Metric
R202: 1k; R_0402_1005Metric
R203, R204: 4k7; R_0402_1005Metric
U201: Wio-E5; WIO-E5; MPN 114993120

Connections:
+BATT: C201.1, C202.1, J202.1, Q101.2 (S), R103.1, R201.1, R203.1, R204.1, U201.1 (VCC); also elsewhere on the board
/MCU/BATT_VSENSE: C107.1, R103.2, R104.1, U201.24 (PB13)
/MCU/DBG_TX: J202.6, U201.12 (PC1)
/MCU/LORA_RF: J201.1 (In), U201.15 (RFIO)
/MCU/STATUS_LED: R202.1, U201.21 (PA9)
/MCU/SWCLK: J202.4, U201.4 (PA14)
/MCU/SWDIO: J202.3, U201.3 (PA13)
/MCU/VBATT_IN: J101.1, Q101.3 (D)
GND: C107.2, C201.2, C202.2, C204.2, D201.1 (K), J101.2, J201.2 (Ext), J202.2, Q101.1 (G), R104.2, U201.2 (GND), U201.14 (GND), U201.16 (GND), U201.22 (GND); also elsewhere on the board
GNSS_ONOFF: U201.13 (PC0); also elsewhere on the board
GNSS_PPS: U201.27 (PA10); also elsewhere on the board
GNSS_RX: U201.19 (PA2); also elsewhere on the board
GNSS_TX: U201.18 (PA3); also elsewhere on the board
LIGHTNING_IRQ: U201.23 (PA0); also elsewhere on the board
NRST: C204.1, J202.5, R201.2, U201.17 (RST)
unnamed: D201.2 (A), R202.2
PM_CS: U201.6 (PA15)
PM_IRQ: U201.25 (PB9); also elsewhere on the board
RADIO_CS: U201.26 (PB14); also elsewhere on the board
RADIO_IRQ: U201.20 (PB10); also elsewhere on the board
RADIO_RST: U201.5 (PB15); also elsewhere on the board
SCL: R203.2, U201.10 (PB6); also elsewhere on the board
SDA: R204.2, U201.9 (PB7); also elsewhere on the board
SPI_MISO: U201.7 (PB4); also elsewhere on the board
SPI_MOSI: U201.11 (PB5); also elsewhere on the board
SPI_SCK: U201.8 (PB3); also elsewhere on the board

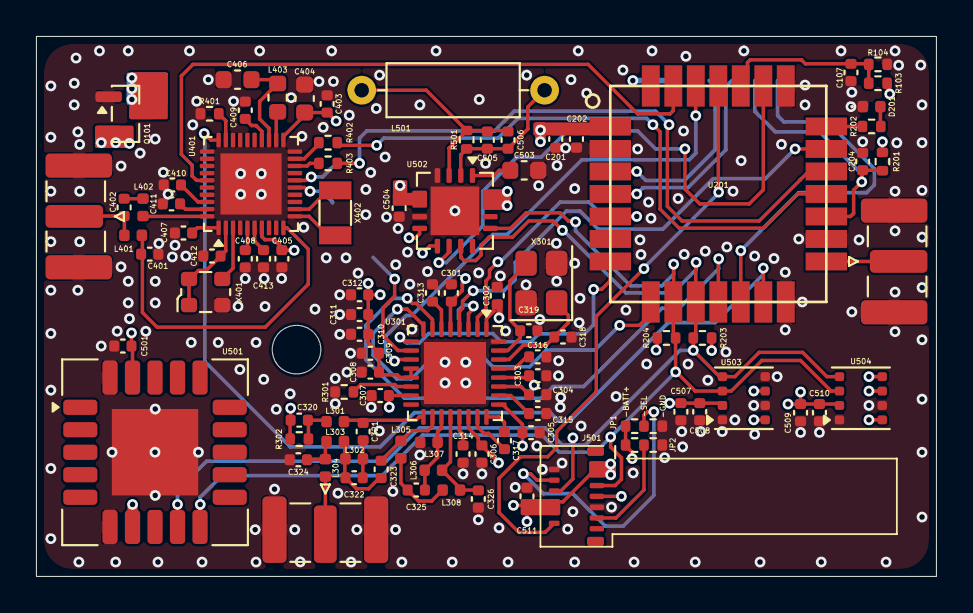
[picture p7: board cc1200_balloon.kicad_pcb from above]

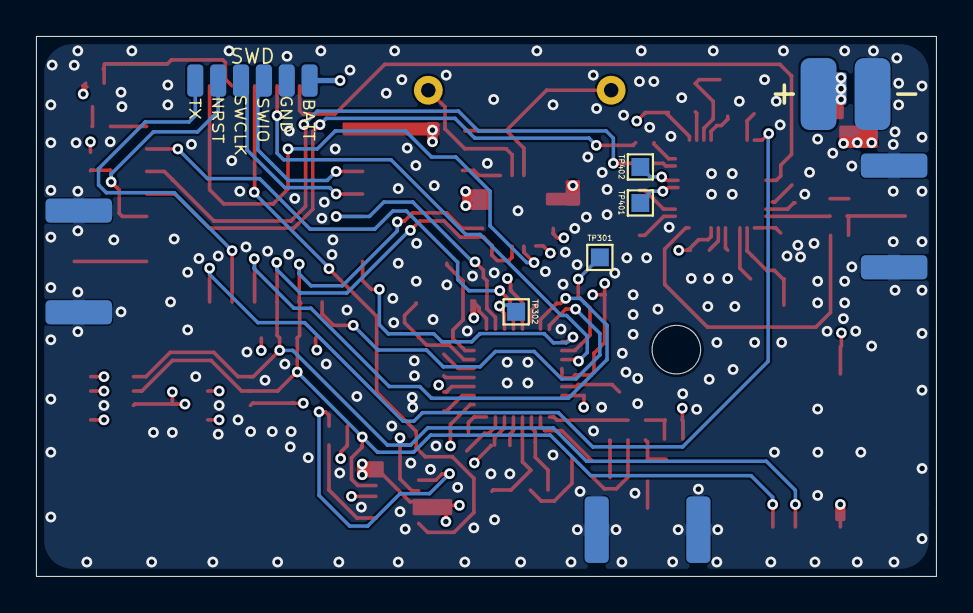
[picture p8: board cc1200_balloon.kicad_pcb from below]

Board: 4 copper layers, 50.0 x 30.0 mm, 105 parts (6 on the bottom side), 72 nets.

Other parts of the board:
H102, H103, H104: M2.5; MountingHole_2.7mm_M2.5_ISO7380

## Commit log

2026-08-31 Add generated schematic set, build pipeline, and BOM
    First commit of the actual design. The hierarchy (power, mcu, radio, gnss,
    sensors) is generated from sheets/*.json by build.sh: kicad-vis places each
    sheet, tools/flowbridge.ts routes it, and a chain of guards checks globals,
    shorted rails, footprint resolution, frame fit, and the netlist against the
    source JSON before a full-hierarchy ERC run. Libraries, 3D models, and the
    DigiKey-sourced BOM are generated too.
    Also fixes global label text justification. Every global label rendered with
    its name pushed against the top of the flag outline rather than centered in
    it. A global label centers its text vertically and takes a horizontal
    justif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
    [Forest-Balloon.csv, at6558r_qfn40.scad, cc1200_balloon.kicad_pcb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]
2026-08-31 Remove the buck-boost: run straight off a 3.6 V max cell
    The TPS63001 and its inductor come out and the battery drives the board
    directly, so the rail is renamed +3V3 -> +BATT on every sheet: a net called
    3V3 that is really the cell is the kind of label someone connects a charger
    to.
    SW101 used to switch the converter's EN pin, which is why it was never in
    series with the load - the C&K JS series is rated 300 mA and this board
    peaks past that. With no EN pin it now drives the gate of Q102, a second
    DMG3401LSN-7 back to back with the reverse-block Q101. Q101 keeps its source
    on the load side so its body diode conducts forward, which is exactly why it
    cannot also be the switch; Q102 faces the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
    [cc1200_balloon.kicad_sch, digikey_bom.csv, gnss.kicad_sch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]
2026-09-06 Demote sheet-local global labels to local labels
    kicad-vis emits a global label for every net that spans two placement
    groups, whether or not the net leaves the sheet. That left 40 flags on
    nets private to one sheet - crystal pairs, the CC1200 PA/LNA nodes, the
    AT6558R internal supply and test pins, SWD - each one a short waiting for
    another sheet to reuse the name, and none of them buying any reach.
    tools/localize.ts demotes a name only when it cannot reach past its sheet:
    not a declared inter-sheet net, not the name of a power symbol anywhere in
    the design, and global on exactly one sheet. The power-symbol exclusion is
    the subtle one: the radio sheet carried a global "+BATT" beside power: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
2026-09-06 Regenerate MCU, power and radio sheets after the label demotion
    Output of the committed localize.ts and fixlabels.ts that had not been
    written back: SWDIO, SWCLK, STATUS_LED and DBG_TX on the MCU sheet and the
    CC1200 oscillator and RF nets on the radio sheet drop from global labels to
    local ones, and one power-sheet label picks up the right horizontal justify
    for its rotation.
    No netlist change.
    [mcu.kicad_sch, power.kicad_sch, radio.kicad_sch]
2026-09-06 Rewire the GNSS to the real AT6558R-5N32 pinout
    The receiver was wired from an invented pinout. Pin names the part does not
    have (VANT_IN, VDD_POR, BBLDO_OUT, VDX, AVDD), numbers to match, and
    comments citing data sheet sections that do not exist. Not one of the 40
    pins was on the right pad.
    Every gate in build.sh passed the whole time, because every gate compares
    the design to sheets/gnss.json and that file was the thing that was wrong.
    ERC, the netlist compare, footprint resolution and the frame fit all agree
    happily about a receiver wired to a part that does not exist.
    Rebuilt against the data sheet (DS-AT6558-R v1.0):
    - Section 3.2.1 supply scheme: +BATT into VDD_IO (7) and DX_IN (21)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
    [gnss.kicad_sch]
2026-09-06 Adjust schematic
    [cc1200_balloon.kicad_pcb]
2026-09-08 Update schematic wiring
    [cc1200_balloon.kicad_pcb, cc1200_balloon.kicad_sch, gnss.kicad_sch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]
2026-09-08 Adjust layout and schematic
    [cc1200_balloon.kicad_pcb, gnss.kicad_sch]
2026-09-10 Clean up schematic. Add component groups to PCB.
    [cc1200_balloon.kicad_pcb, gnss.kicad_sch, mcu.kicad_sch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]
2026-09-10 Add schematic review report
    Reviews the schematic set at 0d6f3e7 against sheets/*.json, the TeleMini
    reference design and the AT6558R data sheet.
    Two blocking defects, both introduced by the hand-edit in 0d6f3e7:
    - power.kicad_sch is empty. Ten parts were deleted, including SW101, Q102
    and the soft-start network, so the board cannot be switched off and has
    no soft start; D101, C101, C104, C106 and C203 went with them, taking
    42 uF of the rail's 76 uF.
    - SCL and SDA are swapped at all four I2C devices. The MCU end is correct
    and every device end is wrong. sheets/sensors.json has it right, so the
    fix is two global labels in sensors.kicad_sch.
    ERC reports zero violations for both,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
2026-09-10 Add ranked CC1200 layout length priorities
    Ranks the CC1200's eighteen placement constraints by how much a millimetre
    costs at each node, with a target and the current measured distance for
    each.
    The ordering falls out of where each millimetre sits electrically rather
    than from signal type: the GND_EP via array leads because it defines the
    return path everything else is measured against, the four DCPL pins
    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
2026-09-11 Inital routing
    [cc1200_balloon.kicad_pcb, gnss.kicad_sch, radio.kicad_sch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]
2026-09-11 More routing.
    [cc1200_balloon.kicad_pcb]
2026-09-14 Route, mostly done.
    [cc1200_balloon.kicad_pcb, sensors.kicad_sch]
2026-09-15 More routing, adjusting traces. Layout silkscreen.
    [cc1200_balloon.kicad_pcb]
2026-09-15 Small adjustments.
    [cc1200_balloon.kicad_pcb, mcu.kicad_sch, power.kicad_sch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]
2026-09-15 Fix DRC errors.
    [cc1200_balloon.kicad_pcb, cc1200_balloon.kicad_sch, sensors.kicad_sch]
2026-09-15 Add missing files.
    [AS3935-BQFT-Extrude.step, SCD40.step]
2026-09-15 Board review, part fields on every symbol, DigiKey BOM regenerated from the schematic
    Full review of the routed board against the data sheets (BOARD_REVIEW.md).
    Blocking: X401 TCXO pin 1 tied to VX_OUT while every candidate part has
    GND or NC there, and the named Kyocera part is six-pad; BMV080 address
    pins float with the jumpers open; BMV080 VDDL out of its 3.3 V window on
    the unregulated rail. Major: rail bulk down to about 12 uF, crystal 7 mm
    from the CC1200, single-spoke RF grounds, three mounting holes off-board,
    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
2026-09-20 Add 10uF caps for sensors.
2026-09-21 Board review of the patch/LNA front end, the burn channel and the TCXO
    Full review at 3c0c6dd. 19 items, 5 blocking:
    - Q1 is drawn with Simulation_SPICE:PMOS, whose pins are 1=D 2=G 3=S, on a
    SOT-523 land. Every real SOT-523 MOSFET is 1=G 2=S 3=D, so +BATT lands on
    the drain, the burn load on the gate and PA15 on the source. No MPN either.
    - Q1's gate has no pull-up, so nothing holds a high-side P-FET off while the
    MCU is in reset. The failure mode is an unintended cutdown.
    - The ALND-WB-0014 has neither the 8.2 nH input match its data sheet requires
    nor an input DC block.
    - The 15x15 mm patch reaches 0.09 mm from the board edge, against a part
    characterized on a 50x50 mm ground p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
2026-09-22 Correct review item 3: the LNA match is a series 8.2 nH, no input DC block
    Read the ALND-WB-0014 evaluation board schematic at 600 dpi instead of the
    low-resolution render. The RF path has exactly one element in it, an 8.2 nH
    in series ahead of RFIN. The three capacitors in the evaluation board BOM
    are all shunt bypasses, C1 and C3 on VCC and C2 on EN, not the port DC
    blocks the first pass took them for.
    So no input DC block is needed on this board: ANT_BIAS feeds VCC and EN
    rather than the RF line, and the patch feed pin is a DC open. C402 on the
    output stays required, since the LNA output carries its own bias and the
    AT6558R limits RF_IN to 1.2 V DC.
    Adds the cut-tape sourcing (LQW15AN8N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
2026-09-22 Re-check 2026-09-22: three blocking items closed, three new ones
    Fixed since the review:
    - Q1 pin mapping is now gate on pad 1, source on pad 2, drain on pad 3,
    the standard SOT-523 arrangement, with the footprint rotated to suit.
    - R205 100k gate pull-up added and placed 1.27 mm from Q1.
    - L404 8.2 nH added in series 0.87 mm from RFIN, with the patch feed
    upstream. That is the Abracon reference topology, and the 1 nF that was
    briefly in the path is gone, which is correct.
    - GNSS_ONOFF under the patch is down from 18.9 mm to 3.8 mm.
    New, and all three are the same class as item 5:
    - R205 is valued 100k but carries RC0402FR-0710KL, the 10k part.
    - L404 is valued 8n2 but carries LQW15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
2026-09-22 Add pullup on mosfet.
2026-09-22 Regenerate the DigiKey BOM against the current board
    tools/parts.json gained the seven parts it was missing: the NDK TCXO, the
    Abracon LNA, the AC33154-1T patch, a 1n0 C0G, an 8.2 nH, a 10 uF 0402 and a
    SOT-523 P-FET for the burn channel. The off-board active antenna that the
    on-board patch replaced is gone.
    resolve() now cross-checks Value against MPN. A symbol whose value has a
    generic entry must carry that entry's part number, so editing a value and
    leaving a copied part number behind is an error instead of a wrong line in
    the upload. It caught all five live instances: R205 and L404 carried the
    part numbers of a 10k and a 6.8 nH, and C512, C513 and C515 carried a 1 uF.
    gen_digikey_bom.py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
2026-09-22 Sync part numbers onto the board and make the custom rules actually fire
    set_part_fields.py run with KiCad closed, so the corrected part numbers are
    now mirrored onto the footprints. Schematic parity is back to 0 and the
    netlist is unchanged at 100 nets. Q1 and C416 gained explicit MPN fields on
    the way, so the burn FET choice is visible in the schematic rather than only
    in tools/parts.json.
    The custom rule file was not doing what it looked like it was doing:
    (condition "A.Type == 'zone' && B.Parent.Reference == 'J401'")
    The type token is 'Zone' and is case sensitive, and a footprint is matched
    with memberOfFootprint(), not Parent.Reference. KiCad reports neither
    mistake, and ignores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
2026-09-22 Compare the as-built power rail with an LDO and with switched domains
    A linear regulator saves no charge; the sleep floor is 271 uA, 200 uA of
    it the SCD40 idling. Swapping to the SCD41, a 1M/1M divider and putting
    the BMV080 behind an EN-switched TPS7A20 brings it to 26 uA.
2026-11-01 Shorten README to a summary and the day-to-day mise tasks
    Block diagram, sheet list, power rail, pin map and interfaces move to
    ARCHITECTURE.md; the power rail ASCII line becomes a mermaid flowchart.
    The pre-flight limitations move to TODO.md. Everything else already lived
    in BOARD_REVIEW.md, BOM.md, POWER_OPTIONS.md, the tool docstrings or the
    untracked notes. New mise tasks: erc, drc, fields-check, fields, bom,
    power, test; build/ holds the ERC and DRC reports.
    Claude-Session: https://claude.ai/code/session_01RCi4N9PFBWEhr8dNmqPWBS
